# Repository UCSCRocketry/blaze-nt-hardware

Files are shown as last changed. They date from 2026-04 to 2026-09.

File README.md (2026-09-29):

# Blaze-NT Avionics System

UCSC Rocketry's high-power rocket flight computer and data acquisition system.

## Overview

The Blaze-NT is a complete avionics system designed for high-power rocket
applications. It provides flight data logging, sensor monitoring, and telemetry
capabilities for UCSC Rocketry team's launch vehicles.

**Current Status**: Prototype hardware has been flight-tested. This repository
contains the schematic revision for the next hardware iteration.

## Features

- **Flight Data Logging**: High-rate sensor data acquisition and storage
- **Telemetry**: 433MHz radio communication for real-time data downlink
- **Sensor Suite**:
  - 9-axis IMU (accelerometer, gyroscope, magnetometer)
  - Barometric pressure sensor for altitude
  - Discrete accelerometer for high-g measurements
- **Power Management**: Battery monitoring and regulated power distribution
- **Microcontroller**: STM32F411 ARM Cortex-M4 processor
- **Firmware**: Arduino framework compatibility

## Project Structure

This KiCad project uses a hierarchical schematic design with separate sheets for
each subsystem:

```
Blaze-NT/
├── Blaze-NT.kicad_sch          # Top-level schematic (team lead managed)
├── microcontroller.kicad_sch   # STM32F411 and peripherals (team lead managed)
├── power-managment.kicad_sch   # Power regulation and distribution (power team)
├── sensors.kicad_sch           # Sensor interfaces and signal conditioning (sensors team)
├── Radio.kicad_sch             # 433MHz telemetry radio (radio team)
├── Blaze-NT.kicad_pro          # Project file
├── avionics-library/           # Custom component library (git submodule)
└── README.md
```

## Hardware Components

### Main Processor

- **STM32F411**: ARM Cortex-M4 microcontroller running the Arduino framework

### Radio System

- **433MHz Transceiver**: RFM69HCW for telemetry communication
- **Antenna**: External 433MHz antenna connector

### Sensors

- **IMU**: LSM9DS1 9-axis inertial measurement unit
- **Barometer**: MS5611 high-precision pressure sensor
- **High-G Accelerometer**: KX134 for high-acceleration events

### Power Management

- **Voltage Regulators**: Integreated bucks for efficient power conversion
- **Battery Monitoring**: Voltage and current sensing capabilities

## Development Workflow

### Team-Based Development

This project is designed for collaborative development with the following roles:

**Team Lead Responsibilities:**

- Manages top-level schematic (`Blaze-NT.kicad_sch`)
- Manages microcontroller sheet (`microcontroller.kicad_sch`)
- Coordinates integration between subsystems
- Handles final schematic review and approval

**Subteam Responsibilities:**

- **Power Team**: Works on `power-managment.kicad_sch`
- **Sensors Team**: Works on `sensors.kicad_sch`
- **Radio Team**: Works on `Radio.kicad_sch`
- Each team only modifies their assigned schematic sheet

### Version Control Notes

**Important**: KiCad schematic files are binary and do not merge well. When
conflicts occur:

1. **Latest Version Wins**: The newest schematic file will override older
   versions in merges
2. **Communication is Key**: Teams must coordinate changes to avoid overwriting
   work
3. **Branch Strategy**: Use feature branches for significant changes
4. **Regular Integration**: Team lead regularly integrates subteam changes

#### Resolving Merge Conflicts with Schematics

When pulling changes from main and conflicts occur in schematic files, you may need to choose which version to keep:

**To keep your branch's version of a schematic:**

```bash
# After git pull results in conflicts
git checkout --ours <schematic-file>.kicad_sch
git add <schematic-file>.kicad_sch
git commit -m "Resolve merge conflict: keep branch version of <schematic-file>"
```

**To keep the main branch's version of a schematic:**

```bash
# After git pull results in conflicts  
git checkout --theirs <schematic-file>.kicad_sch
git add <schematic-file>.kicad_sch
git commit -m "Resolve merge conflict: use main version of <schematic-file>"
```

**Example for power team keeping their version:**

```bash
git checkout --ours power-managment.kicad_sch
git add power-managment.kicad_sch
git commit -m "Resolve merge conflict: keep branch version of power-managment schematic"
```

**Important**: Always communicate with the team lead before resolving conflicts to ensure important changes aren't lost.

### Git Workflow

```bash
# Clone with submodules
git clone --recurse-submodules <repository-url>

# Or initialize submodules after cloning
git submodule update --init --recursive

# Create feature branch for subsystem changes
git checkout -b feature/power-improvements

# Make changes to your assigned sheet only
# Commit and push changes
git add power-managment.kicad_sch
git commit -m "Improve power regulation efficiency"
git push origin feature/power-improvements
```

## Build Instructions

### Prerequisites

- KiCad 9.0 or later
- Git for version control

### Opening the Project

1. Clone the repository with submodules:
   ```bash
   git clone --recurse-submodules https://github.com/UCSCRocketry/blaze-nt-hardware.git
   ```

2. Open KiCad
3. Open the project file: `Blaze-NT.kicad_pro`

### Working with Schematics

1. **Team Lead**: Open and edit `Blaze-NT.kicad_sch` and
   `microcontroller.kicad_sch`
2. **Subteams**: Open only your assigned schematic sheet
3. **Symbol Library**: Custom symbols are in
   `avionics-library/Avionics_Symbols.kicad_sym`
4. **Footprints**: Custom footprints are in
   `avionics-library/Avionics_Feet.pretty/`

## Component Library

This project uses a custom component library stored as a git submodule:

- **Repository**: `UCSCRocketry/avionics-library`
- **Symbols**: `avionics-library/Avionics_Symbols.kicad_sym`
- **Footprints**: `avionics-library/Avionics_Feet.pretty/`

To update the library:

```bash
git submodule update --remote avionics-library
git add avionics-library
git commit -m "Update avionics library"
```

## Contribution Guidelines

### For Subteams

1. **Stay in Your Lane**: Only modify your assigned schematic sheet
2. **Test Changes**: Verify electrical rules check (ERC) passes before
   committing
3. **Document Changes**: Update schematic notes and component values
4. **Coordinate**: Communicate with team lead before major changes

### For Team Lead

1. **Review Changes**: Check all subteam contributions before integration
2. **Maintain Top Sheet**: Update hierarchical sheet references as needed
3. **Version Control**: Manage merge conflicts and coordinate integration
4. **Quality Control**: Ensure overall schematic integrity and consistency

### Commit Message Format

Use clear, descriptive commit messages:

```
subsystem: brief description

Detailed explanation of changes if needed.
```

Examples:

- `power: add battery voltage monitoring`
- `sensors: update IMU filter configuration`
- `radio: improve antenna matching network`

## File Formats

- **Schematics**: `.kicad_sch` (binary format)
- **Project Settings**: `.kicad_pro` (JSON format)
- **Project Local**: `.kicad_prl` (local settings, gitignored)
- **Symbol Library**: `.kicad_sym` (binary format)
- **Footprints**: `.kicad_mod` (text format)

## Troubleshooting

### Common Issues

1. **Missing Symbols**: Ensure `avionics-library` submodule is initialized
2. **Schematic Won't Open**: Check KiCad version compatibility
3. **ERC Errors**: Review net connections and component properties

### Getting Help

- Contact the project team lead for integration issues
- Consult KiCad documentation for tool-specific questions
- Review existing schematic sheets for design patterns

## License

This project is proprietary to UCSC Rocketry team. Do not distribute without
permission.

---

**Note**: This hardware has been flight-tested on prototype vehicles. Always
perform thorough ground testing before flight use.

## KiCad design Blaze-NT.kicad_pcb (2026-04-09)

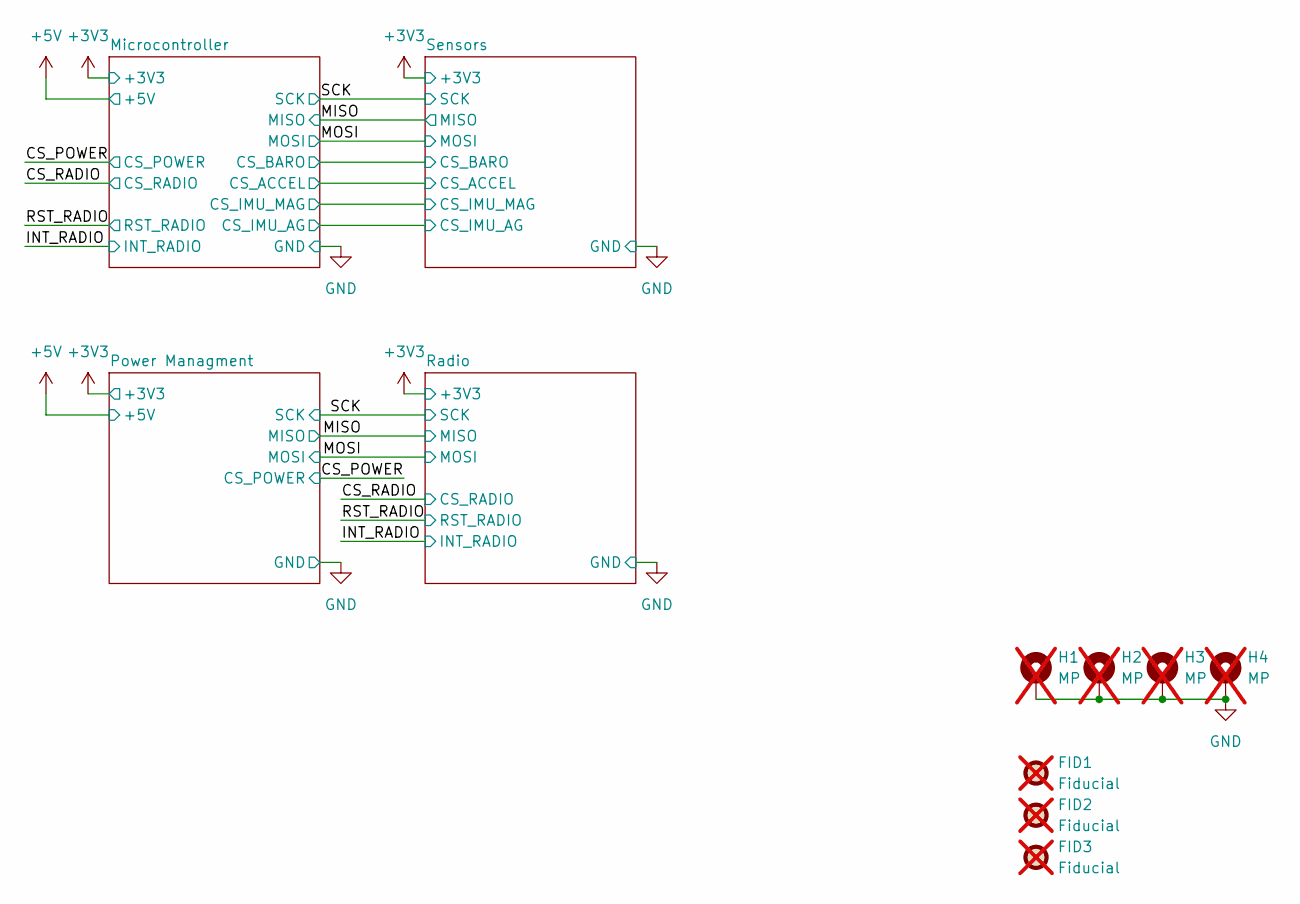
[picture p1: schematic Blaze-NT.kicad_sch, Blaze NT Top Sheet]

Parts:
FID1, FID2, FID3: Fiducial; JLC_Fiducial; not fitted
H1, H2, H3, H4: MP; MountingHole_3.2mm_M3_ISO7380_Pad; not fitted

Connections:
GND: H1.1, H2.1, H3.1, H4.1; also elsewhere on the board

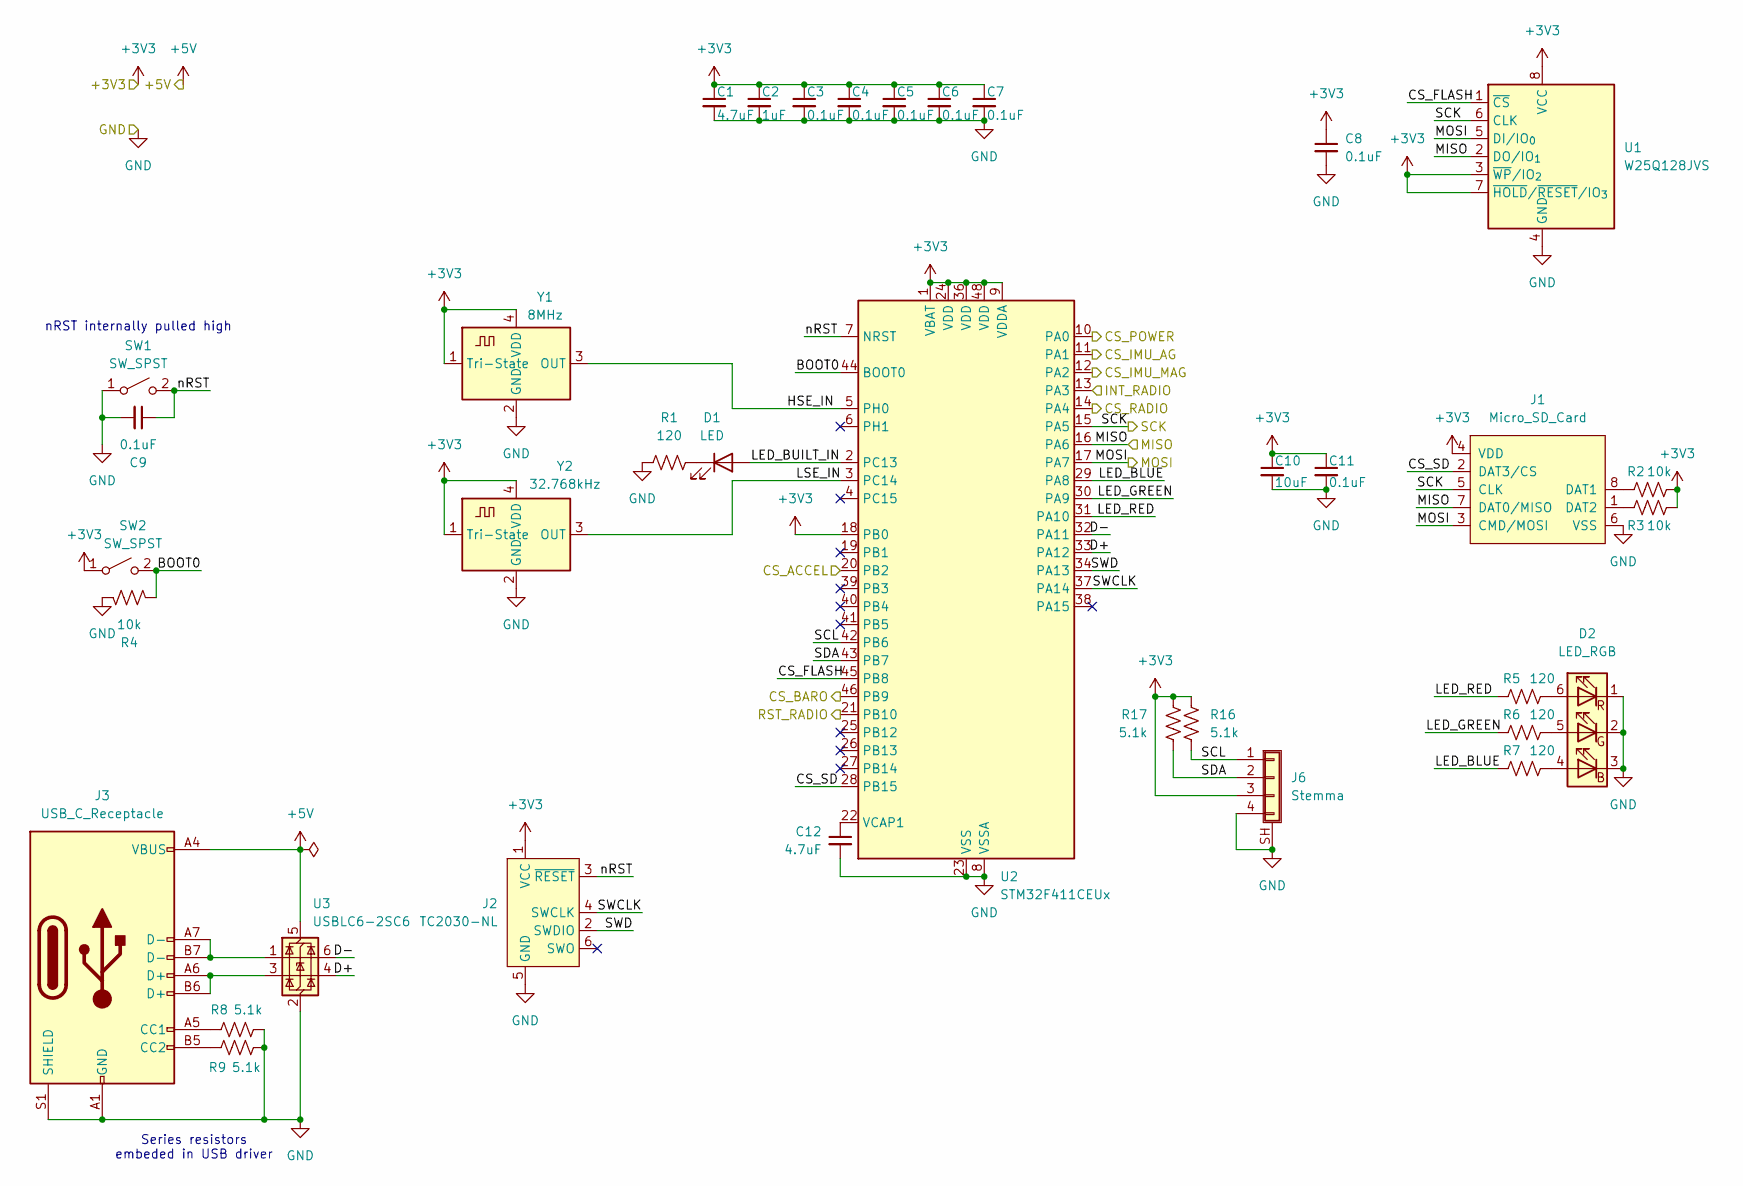
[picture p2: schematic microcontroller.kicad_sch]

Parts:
C1, C12: 4.7uF; C_0603_1608Metric; LCSC C19666
C2: 1uF; C_0603_1608Metric; LCSC C15849
C3, C4, C5, C6, C7, C8, C9, C11: 0.1uF; C_0603_1608Metric; LCSC C14663
C10: 10uF; C_0603_1608Metric; LCSC C96446
D1: LED; LED_0603_1608Metric; LCSC C2994781
D2: LED_RGB; LED_RGB_5050-6; LCSC C784540
J1: Micro_SD_Card; microSD_HC_Molex_47219-2001
J2: TC2030-NL; Tag-Connect_TC2030-IDC-NL_2x03_P1.27mm_Vertical
J3: USB_C_Receptacle; USB_C_Receptacle_GCT_USB4105-xx-A_16P_TopMnt_Horizontal; LCSC C3025063
J6: Stemma; JST_SH_SM04B-SRSS-TB_1x04-1MP_P1.00mm_Horizontal; LCSC C160404
R1, R5, R6, R7: 120; R_0603_1608Metric; LCSC C22787
R2, R3, R4: 10k; R_0603_1608Metric; LCSC C98220
R8, R9, R16, R17: 5.1k; R_0603_1608Metric; LCSC C2907044
SW1, SW2: SW_SPST; SW_SPST_B3U-1000P-B; LCSC C231329
U1: W25Q128JVS; SOIC-8_5.3x5.3mm_P1.27mm; LCSC C97521
U2: STM32F411CEUx; QFN-48-1EP_7x7mm_P0.5mm_EP5.6x5.6mm; LCSC C60420
U3: USBLC6-2SC6; SOT-23-6; LCSC C7519
Y1: 8MHz; Oscillator_SMD_Abracon_ASCO-4Pin_1.6x1.2mm; LCSC ASCO-8.000MHZ-EK-T3
Y2: 32.768kHz; Oscillator_SMD_Abracon_ASCO-4Pin_1.6x1.2mm; Digikey 50-ECS-327MV-CN-TRCT-ND

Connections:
+3V3: C1.1, C2.1, C3.1, C4.1, C5.1, C6.1, C7.1, C8.1, C10.1, C11.1, J1.4 (VDD), J2.1 (VCC), J6.3, R2.2, R3.2, R16.1, R17.1, SW2.1 (A), U1.3 (~WP/IO_{2}), U1.7 (~HOLD/~RESET/IO_{3}), U1.8 (VCC), U2.1 (VBAT), U2.9 (VDDA), U2.18 (PB0), U2.24 (VDD), U2.36 (VDD), U2.48 (VDD), Y1.1 (Tri-State), Y1.4 (VDD), Y2.1 (Tri-State), Y2.4 (VDD); also elsewhere on the board
+5V: J3.A4 (VBUS), J3.A9 (VBUS), J3.B4 (VBUS), J3.B9 (VBUS), U3.5 (VBUS); also elsewhere on the board
/CS_POWER: U2.10 (PA0); also elsewhere on the board
/CS_RADIO: U2.14 (PA4); also elsewhere on the board
/INT_RADIO: U2.13 (PA3); also elsewhere on the board
/MISO: J1.7 (DAT0/MISO), U1.2 (DO/IO_{1}), U2.16 (PA6); also elsewhere on the board
/MOSI: J1.3 (CMD/MOSI), U1.5 (DI/IO_{0}), U2.17 (PA7); also elsewhere on the board
/Microcontroller/BOOT0: R4.2, SW2.2 (B), U2.44 (BOOT0)
/Microcontroller/CS_ACCEL: U2.20 (PB2); also elsewhere on the board
/Microcontroller/CS_BARO: U2.46 (PB9); also elsewhere on the board
/Microcontroller/CS_FLASH: U1.1 (~CS), U2.45 (PB8)
/Microcontroller/CS_IMU_AG: U2.11 (PA1); also elsewhere on the board
/Microcontroller/CS_IMU_MAG: U2.12 (PA2); also elsewhere on the board
/Microcontroller/CS_SD: J1.2 (DAT3/CS), U2.28 (PB15)
/Microcontroller/D+: U2.33 (PA12), U3.4 (I/O2)
/Microcontroller/D-: U2.32 (PA11), U3.6 (I/O1)
/Microcontroller/HSE_IN: U2.5 (PH0), Y1.3 (OUT)
/Microcontroller/LED_BLUE: R7.1, U2.29 (PA8)
/Microcontroller/LED_BUILT_IN: D1.2 (A), U2.2 (PC13)
/Microcontroller/LED_GREEN: R6.1, U2.30 (PA9)
/Microcontroller/LED_RED: R5.1, U2.31 (PA10)
/Microcontroller/LSE_IN: U2.3 (PC14), Y2.3 (OUT)
/Microcontroller/SCL: J6.1, R16.2, U2.42 (PB6)
/Microcontroller/SDA: J6.2, R17.2, U2.43 (PB7)
/Microcontroller/SWCLK: J2.4 (SWCLK), U2.37 (PA14)
/Microcontroller/SWD: J2.2 (SWDIO), U2.34 (PA13)
/Microcontroller/nRST: C9.1, J2.3 (~RESET), SW1.2 (B), U2.7 (NRST)
/RST_RADIO: U2.21 (PB10); also elsewhere on the board
/SCK: J1.5 (CLK), U1.6 (CLK), U2.15 (PA5); also elsewhere on the board
GND: C1.2, C2.2, C3.2, C4.2, C5.2, C6.2, C7.2, C8.2, C9.2, C10.2, C11.2, C12.2, D2.1 (RK), D2.2 (GK), D2.3 (BK), J1.6 (VSS), J1.SHIELD (GND), J2.5 (GND), J3.A1 (GND), J3.A12 (GND), J3.B1 (GND), J3.B12 (GND), J3.S1 (SHIELD), J6.4, J6.SH (Shield), R1.1, R4.1, R8.2, R9.2, SW1.1 (A), U1.4 (GND), U2.8 (VSSA), U2.23 (VSS), U2.35 (VSS), U2.47 (VSS), U2.49 (VSS), U3.2 (GND), Y1.2 (GND), Y2.2 (GND); also elsewhere on the board
unnamed: D1.1 (K), R1.2
unnamed: D2.4 (BA), R7.2
unnamed: D2.5 (GA), R6.2
unnamed: D2.6 (RA), R5.2
unnamed: J1.8 (DAT1), R2.1
unnamed: J1.1 (DAT2), R3.1
unnamed: J3.A5 (CC1), R8.1
unnamed: J3.B5 (CC2), R9.1
unnamed: J3.A6 (D+), J3.B6 (D+), U3.3 (I/O2)
unnamed: J3.A7 (D-), J3.B7 (D-), U3.1 (I/O1)
unnamed: C12.1, U2.22 (VCAP1)

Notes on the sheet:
nRST internally pulled high
Series resistors embeded in USB driver

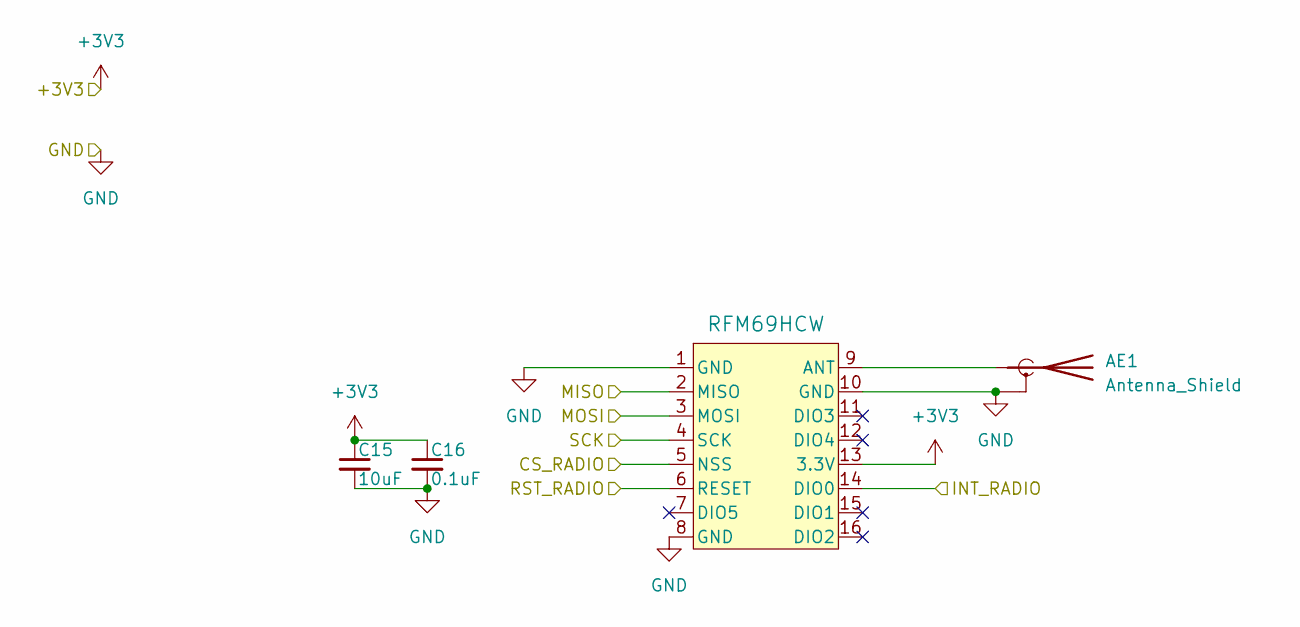
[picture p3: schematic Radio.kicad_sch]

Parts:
AE1: Antenna_Shield; SMA_Samtec_SMA-J-P-H-ST-EM1_EdgeMount; LCSC C5199907
C15: 10uF; C_0603_1608Metric; LCSC C96446
C16: 0.1uF; C_0603_1608Metric; LCSC C14663
U5: RFM69HCW; HOPERF_RFM9XW_SMD; LCSC C2844474

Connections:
+3V3: C15.1, C16.1, U5.13 (3.3V); also elsewhere on the board
/CS_RADIO: U5.5 (NSS); also elsewhere on the board
/INT_RADIO: U5.14 (DIO0); also elsewhere on the board
/MISO: U5.2 (MISO); also elsewhere on the board
/MOSI: U5.3 (MOSI); also elsewhere on the board
/RST_RADIO: U5.6 (RESET); also elsewhere on the board
/SCK: U5.4 (SCK); also elsewhere on the board
GND: AE1.2 (Shield), C15.2, C16.2, U5.1 (GND), U5.8 (GND), U5.10 (GND); also elsewhere on the board
unnamed: AE1.1 (A), U5.9 (ANT)

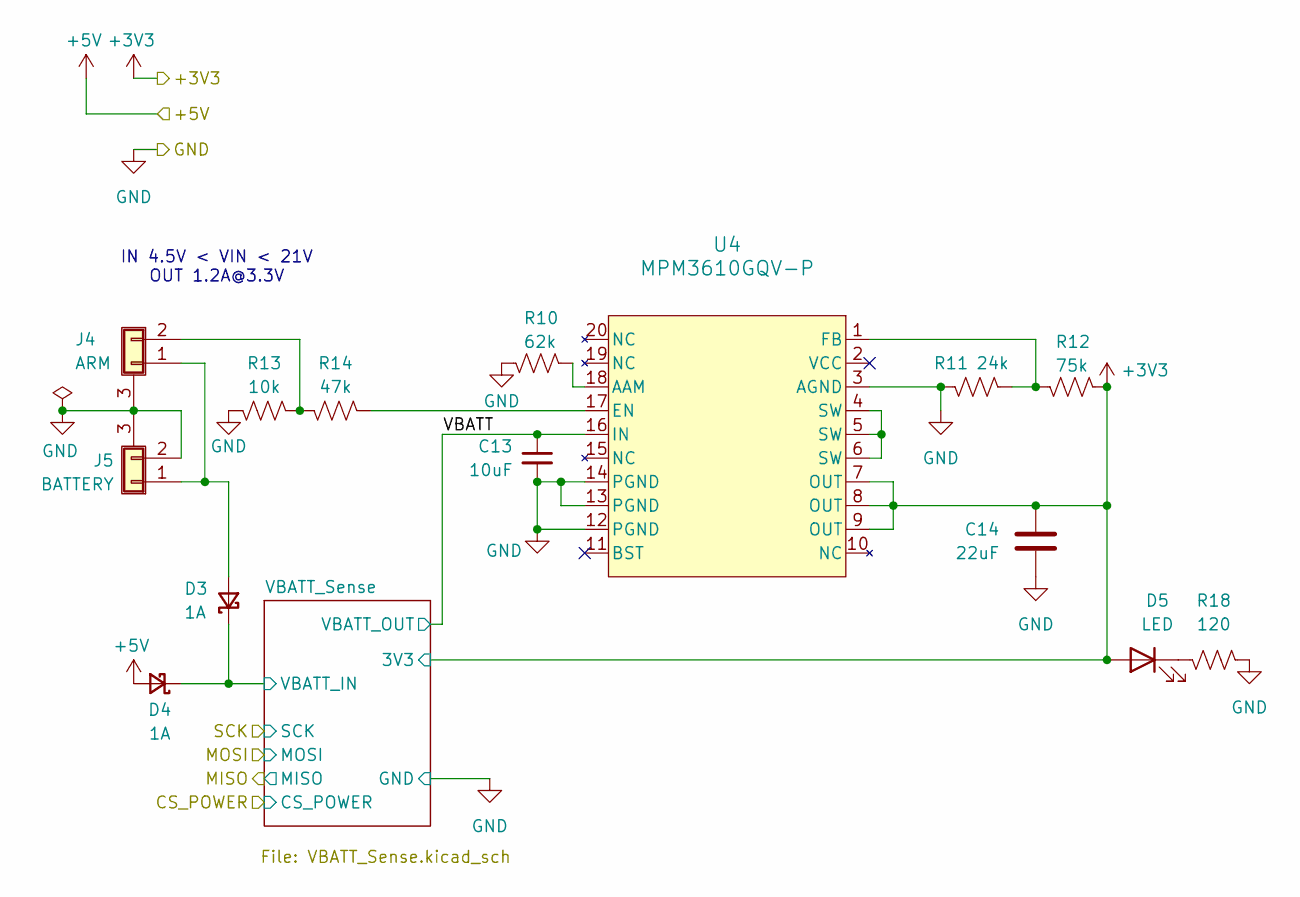
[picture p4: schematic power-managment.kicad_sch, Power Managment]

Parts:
C13: 10uF; C_0603_1608Metric; LCSC C96446
C14: 22uF; C_0603_1608Metric; LCSC C59461
D3, D4: 1A; D_SOD-123F; LCSC C784540
D5: LED; LED_0603_1608Metric; LCSC C2994781
J4: ARM; 0436500205; Digikey WM17581-ND
J5: BATTERY; 0436500205; Digikey WM17581-ND
R10: 62k; R_0603_1608Metric; LCSC C137694
R11: 24k; R_0603_1608Metric; LCSC C137760
R12: 75k; R_0603_1608Metric; LCSC C114636
R13: 10k; R_0603_1608Metric; LCSC C98220
R14: 47k; R_0603_1608Metric; LCSC C105579
R18: 120; R_0603_1608Metric; LCSC C22787
U4: MPM3610GQV-P; MPM3610QGV-P; Digikey 1589-1250-1-ND

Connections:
+3V3: C14.1, D5.2 (A), R12.1, U4.7 (OUT), U4.8 (OUT), U4.9 (OUT); also elsewhere on the board
+5V: D4.2 (A); also elsewhere on the board
/Power Managment/VBATT: C13.1, U4.16 (IN); also elsewhere on the board
/Power Managment/VBATT_Sense/VBATT_IN: D3.1 (K), D4.1 (K); also elsewhere on the board
GND: C13.2, C14.2, J4.3 (Shield), J5.2, J5.3 (Shield), R10.1, R11.2, R13.2, R18.1, U4.3 (AGND), U4.12 (PGND), U4.13 (PGND), U4.14 (PGND); also elsewhere on the board
unnamed: D3.2 (A), J4.1 (Pin_2), J5.1
unnamed: D5.1 (K), R18.2
unnamed: J4.2 (Pin_1), R13.1, R14.2
unnamed: R10.2, U4.18 (AAM)
unnamed: R14.1, U4.17 (EN)
unnamed: R11.1, R12.2, U4.1 (FB)
unnamed: U4.4 (SW), U4.5 (SW), U4.6 (SW)

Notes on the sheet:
IN 4.5V < VIN < 21V OUT 1.2A@3.3V

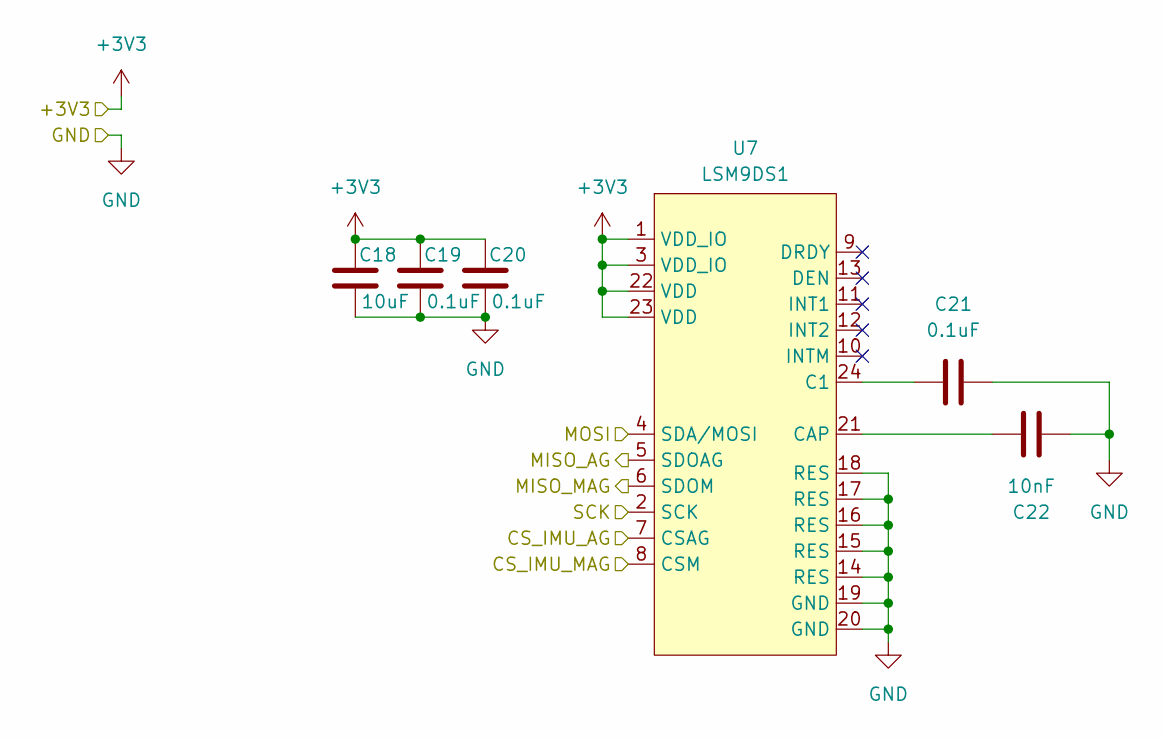
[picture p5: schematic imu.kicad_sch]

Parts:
C18: 10uF; C_0603_1608Metric; LCSC C96446
C19, C20, C21: 0.1uF; C_0603_1608Metric; LCSC C14663
C22: 10nF; C_0603_1608Metric; LCSC C1589
U7: LSM9DS1; PQFN24P43_350X300X102L35X23N; LCSC C2655096

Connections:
+3V3: C18.1, C19.1, C20.1, U7.1 (VDD_IO), U7.3 (VDD_IO), U7.22 (VDD), U7.23 (VDD); also elsewhere on the board
/MISO: U7.5 (SDOAG), U7.6 (SDOM); also elsewhere on the board
/MOSI: U7.4 (SDA/MOSI); also elsewhere on the board
/Microcontroller/CS_IMU_AG: U7.7 (CSAG); also elsewhere on the board
/Microcontroller/CS_IMU_MAG: U7.8 (CSM); also elsewhere on the board
/SCK: U7.2 (SCK); also elsewhere on the board
GND: C18.2, C19.2, C20.2, C21.1, C22.2, U7.14 (RES), U7.15 (RES), U7.16 (RES), U7.17 (RES), U7.18 (RES), U7.19 (GND), U7.20 (GND); also elsewhere on the board
unnamed: C21.2, U7.24 (C1)
unnamed: C22.1, U7.21 (CAP)

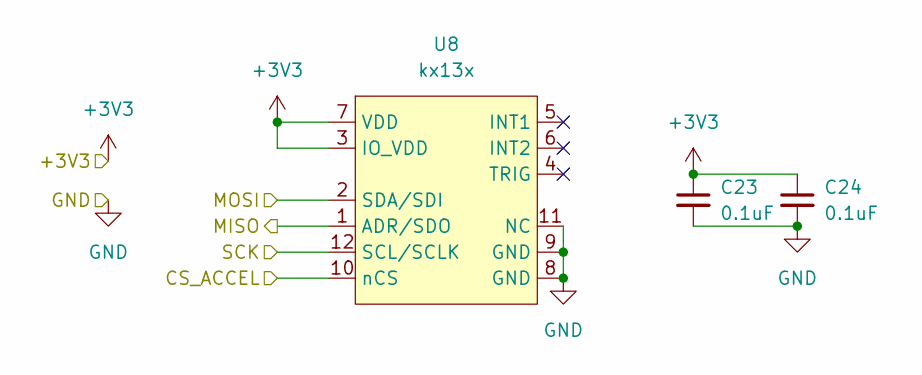
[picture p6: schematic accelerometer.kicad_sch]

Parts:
C23, C24: 0.1uF; C_0603_1608Metric; LCSC C14663
U8: kx13x; XDCR_KX003-1077; LCSC C2157908

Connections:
+3V3: C23.1, C24.1, U8.3 (IO_VDD), U8.7 (VDD); also elsewhere on the board
/MISO: U8.1 (ADR/SDO); also elsewhere on the board
/MOSI: U8.2 (SDA/SDI); also elsewhere on the board
/Microcontroller/CS_ACCEL: U8.10 (nCS); also elsewhere on the board
/SCK: U8.12 (SCL/SCLK); also elsewhere on the board
GND: C23.2, C24.2, U8.8 (GND), U8.9 (GND), U8.11 (NC); also elsewhere on the board

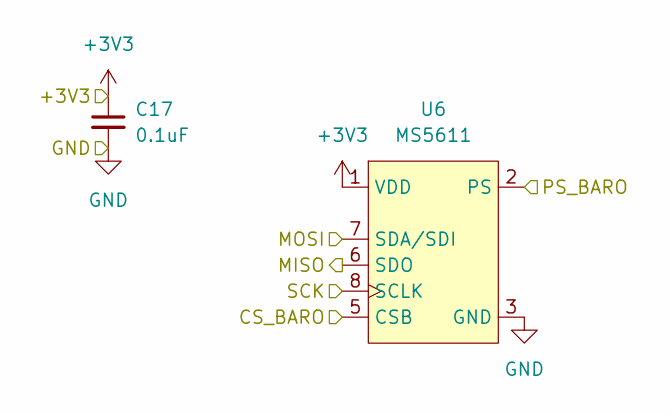
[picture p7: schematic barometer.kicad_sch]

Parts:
C17: 0.1uF; C_0603_1608Metric; LCSC C14663
U6: MS5611; XDCR_MS561101BA03-50; LCSC C15639

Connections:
+3V3: C17.1, U6.1 (VDD); also elsewhere on the board
/MISO: U6.6 (SDO); also elsewhere on the board
/MOSI: U6.7 (SDA/SDI); also elsewhere on the board
/Microcontroller/CS_BARO: U6.4 (CSB), U6.5 (CSB); also elsewhere on the board
/SCK: U6.8 (SCLK); also elsewhere on the board
GND: C17.2, U6.2 (PS), U6.3 (GND); also elsewhere on the board

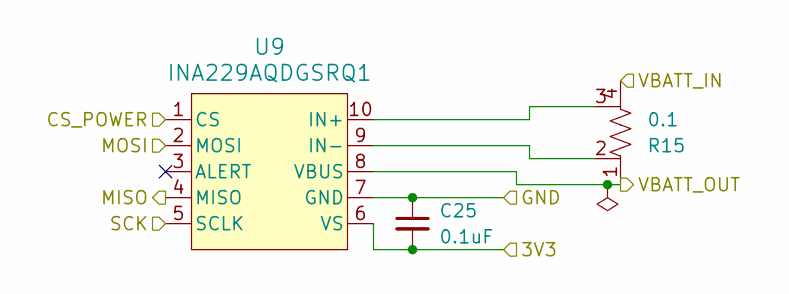
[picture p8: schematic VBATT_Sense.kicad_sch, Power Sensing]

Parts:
C25: 0.1uF; C_0603_1608Metric; LCSC C14663
R15: 0.1; R_Shunt_Ohmite_LVK24; LCSC C6981159
U9: INA229AQDGSRQ1; VSSOP-10_3x3mm_P0.5mm; LCSC C2870151

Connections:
+3V3: C25.2, U9.6 (VS); also elsewhere on the board
/CS_POWER: U9.1 (CS); also elsewhere on the board
/MISO: U9.4 (MISO); also elsewhere on the board
/MOSI: U9.2 (MOSI); also elsewhere on the board
/Power Managment/VBATT: R15.1, U9.8 (VBUS); also elsewhere on the board
/Power Managment/VBATT_Sense/VBATT_IN: R15.4; also elsewhere on the board
/SCK: U9.5 (SCLK); also elsewhere on the board
GND: C25.1, U9.7 (GND); also elsewhere on the board
unnamed: R15.3, U9.10 (IN+)
unnamed: R15.2, U9.9 (IN-)

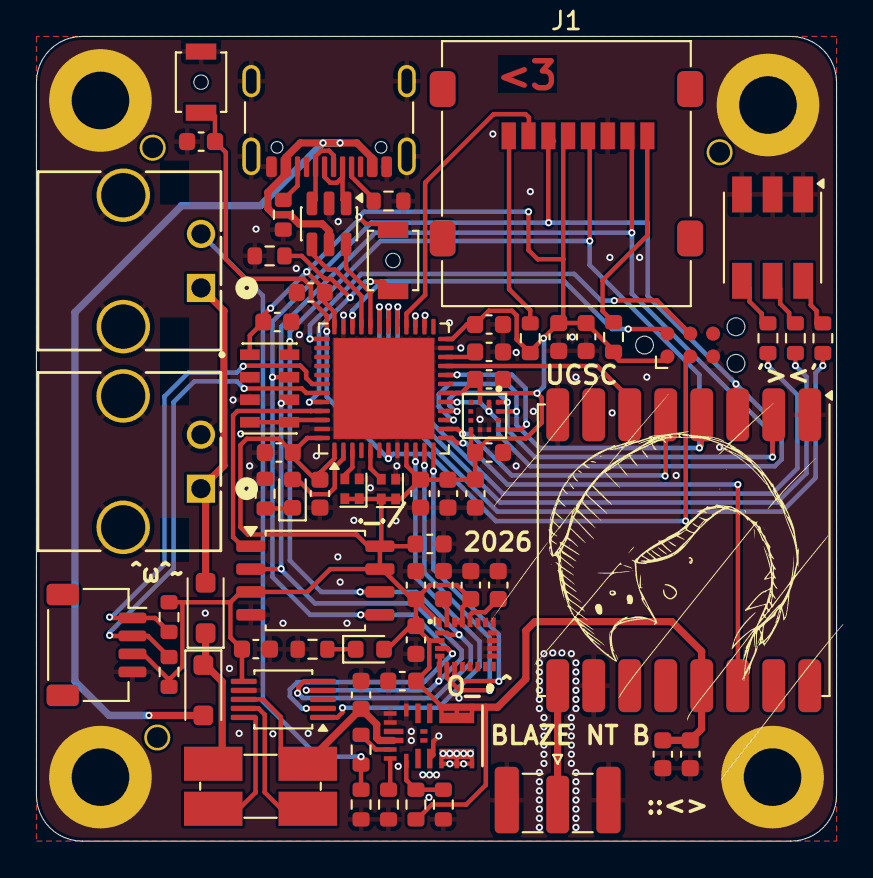
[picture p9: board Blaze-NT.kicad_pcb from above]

Board: 2 copper layers, 44.4 x 44.7 mm, 75 parts (0 on the bottom side), 55 nets.

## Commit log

2026-01-18 Schematic Sheet Setup
    [Blaze-NT.kicad_sch, Radio.kicad_sch, microcontroller.kicad_sch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]
2026-01-18 Added names to sheets
    [Radio.kicad_sch, microcontroller.kicad_sch, power-managment.kicad_sch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]
2026-01-19 MCU Schem capture
    [microcontroller.kicad_sch]
2026-01-19 Added bulk capacitnace
    [Blaze-NT.kicad_sch, Radio.kicad_sch, microcontroller.kicad_sch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]
2026-01-19 Microcontroller topsheet
    [Blaze-NT.kicad_sch]
2026-01-20 Updated heiarchal power labels
    [Blaze-NT.kicad_sch, Radio.kicad_sch, microcontroller.kicad_sch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]
2026-01-20 Moved labels, updated USB conn symbol
    [microcontroller.kicad_sch]
2026-01-23 Fixed MOSI/MISO on SD
    [microcontroller.kicad_sch]
2026-02-05 Merged sensors topsheet
    [sensors.kicad_sch]
2026-02-05 Merges schematics, did annotation
    [Blaze-NT.kicad_sch, Radio.kicad_sch, VBATT_Sense.kicad_sch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]
2026-02-05 Added IMU schematic
    [imu.kicad_sch]
2026-02-05 Connected topsheet
    [Blaze-NT.kicad_sch, VBATT_Sense.kicad_sch, accelerometer.kicad_sch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]
2026-02-05 Footprint selection
    [VBATT_Sense.kicad_sch, accelerometer.kicad_sch, barometer.kicad_sch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]
2026-02-06 Merged radio
    [Radio.kicad_sch]
2026-02-06 Connected radio
    [Blaze-NT.kicad_sch, microcontroller.kicad_sch]
2026-02-06 Radio footprint selection
    [Radio.kicad_sch, VBATT_Sense.kicad_sch, accelerometer.kicad_sch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]
2026-02-07 PCB work
    [Blaze-NT.kicad_pcb, Blaze-NT.kicad_sch, VBATT_Sense.kicad_sch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]
2026-02-07 KX footprint
2026-02-11 Silk updates
    [Blaze-NT.kicad_pcb, microcontroller.kicad_sch]
2026-02-11 Addeed part numbers
    [Blaze-NT.kicad_pcb, Blaze-NT.kicad_sch, Radio.kicad_sch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]
2026-02-11 Added prod files
    [Blaze-NT.kicad_pcb]
2026-02-17 PCB revisions
    [Blaze-NT.kicad_pcb, microcontroller.kicad_sch]
2026-02-18 Added fiducials
    [Blaze-NT.kicad_pcb, Blaze-NT.kicad_sch]
2026-02-18 Added Digikey Components
    [Blaze-NT.kicad_pcb, Blaze-NT.kicad_sch, Radio.kicad_sch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]
2026-04-08 Updated SD card to corrected symbol
    [Blaze-NT.kicad_pcb, microcontroller.kicad_sch]
